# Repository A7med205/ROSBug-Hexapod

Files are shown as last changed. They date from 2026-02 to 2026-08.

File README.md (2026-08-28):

# ROSBug Hexapod

ROSBug is an open-source, Raspberry Pi-based hexapod robot with an onboard
camera, printable CAD, physical-robot software, and a ROS 2 Gazebo simulation.
The Raspberry Pi sends timed points for all 18 joints to a Servo 2040 in
batches over USB. The Servo 2040 runs Pimoroni MicroPython and treats each
batch as an opaque playback job: it validates, calibrates, and applies the
points without knowing whether they were generated by the gait core, posture
core, or another compatible producer.

Hardware and simulation use the same model, inverse kinematics, gait and
posture generators, keyboard mapping, and motion coordinator. Only their
transport adapters and actuator backends differ.

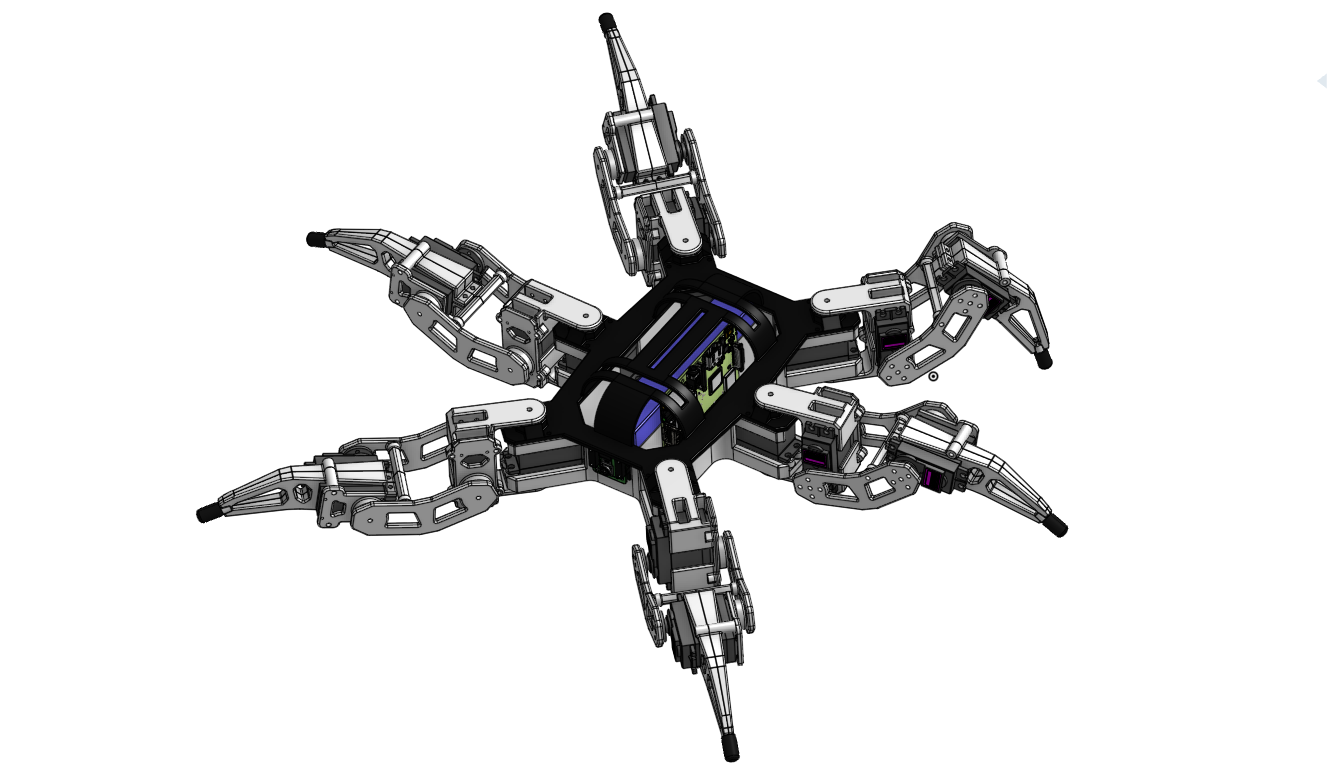
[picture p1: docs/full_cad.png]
Complete ROSBug Hexapod CAD assembly


## Highlights

- Shared, transport-independent Python motion core
- Tripod translation, rotation, diagonal, and orbit gaits
- Smooth elevation, pitch, and roll posture control
- Raspberry Pi to Servo 2040 binary batch protocol
- Pimoroni MicroPython firmware with per-servo calibration
- ROS 2 Humble, Gazebo Sim, RViz, and Docker support
- Editable Onshape CAD and print-ready STL files

## Quick start

### Physical robot

Deploy the runtime directories to the Pi, install the host dependencies, copy
the MicroPython application to the Servo 2040, and start the board interface.
The complete procedure, including BOOTSEL recovery, is in
[Hardware setup](docs/hardware-setup.md).

```bash
python3 -m hardware.board_interface --port /dev/ttyACM0
```

### Docker simulation

On a Linux host with Docker and X11 available:

```bash
./run_sim_docker.sh
```

See [Simulation](docs/simulation.md) for native ROS 2 setup, launch variants,
adapter parameters, and Docker options.

## Documentation

| Topic | Contents |
| --- | --- |
| [Documentation index](docs/README.md) | Task-oriented navigation to every guide |
| [Architecture](docs/architecture.md) | Components, repository layout, and hardware/simulation data flow |
| [Controls](docs/controls.md) | Keyboard commands, operating modes, and posture behavior |
| [Motion model](docs/motion-model.md) | Coordinate frames, IK, gait generation, posture limits, and parameters |
| [Hardware setup](docs/hardware-setup.md) | Pi deployment, dependencies, firmware installation, and startup |
| [Servo 2040](docs/servo2040.md) | MicroPython playback, binary protocol, measured timing, and calibration |
| [Simulation](docs/simulation.md) | ROS 2, Gazebo, RViz, Docker, and simulation parameters |
| [Hardware design](docs/hardware-design.md) | CAD and electronics wiring |
| [Bill of materials](docs/bill-of-materials.md) | Components, printed parts, fasteners, and tools |

## Repository overview

```text
ROSBug-Hexapod/
├── cad/stl/                         printable mechanical parts
├── common/                          shared keyboard input
├── gait_core/                       tripod gait generation
├── posture_core/                    elevation, pitch, and roll generation
├── robot_core/                      model, IK, coordination, and batch types
├── hardware/                        Pi adapter and Servo 2040 MicroPython code
├── ros2_ws/src/hexapod_sim/         ROS 2 simulation package
├── docs/                            guides, diagrams, and demonstrations
├── Dockerfile
├── run_sim_docker.sh
└── requirements.txt
```

## Camera testing

For camera testing, see
[RaspberryPi-WebRTC](https://github.com/TzuHuanTai/RaspberryPi-WebRTC).

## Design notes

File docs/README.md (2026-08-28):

[Project home](../README.md) · Documentation index

# ROSBug documentation

Use this index to find setup instructions, operating guidance, design details,
and technical reference material.

| I want to… | Documentation |
| --- | --- |
| Install and run the physical robot | [Hardware setup](hardware-setup.md) |
| Run Gazebo, RViz, or Docker | [Simulation](simulation.md) |
| Learn the modes and keyboard commands | [Controls](controls.md) |
| Understand the software components and data flow | [Architecture](architecture.md) |
| Understand kinematics, gait, and posture generation | [Motion model](motion-model.md) |
| Inspect the Servo 2040 protocol, playback, and calibration | [Servo 2040](servo2040.md) |
| Inspect the CAD, electronics, and wiring | [Hardware design](hardware-design.md) |
| Find parts, printed components, fasteners, and tools | [Bill of materials](bill-of-materials.md) |

All commands are run from the repository root unless a document explicitly
changes directory.

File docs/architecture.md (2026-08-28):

[Project home](../README.md) · [Documentation index](README.md)

# Architecture

ROSBug uses one transport-independent motion core for the physical robot and
simulation. The adapters differ, but both consume the same timed, 18-joint
`JointBatch` objects.

## Repository layout

```text
ROSBug-Hexapod/
├── cad/stl/                         printable mechanical parts
├── common/
│   └── keyboard_input.py            shared nonblocking keyboard mapping
├── gait_core/
│   └── lite_gait.py                 tripod paths, swings, templates, gait state
├── posture_core/
│   └── posture.py                   elevation, pitch, roll, limits, smoothing
├── robot_core/
│   ├── control.py                   commands and normal/auto/posture modes
│   ├── coordinator.py               shared motion arbitration
│   ├── execution.py                 shared batch-executor result contract
│   ├── feedback.py                  structured command/state feedback
│   ├── model.py                     geometry, frames, fixed-foot transforms, IK
│   └── motion_batch.py              transport-neutral JointBatch and goal IDs
├── hardware/                        physical-robot-only code
│   ├── firmware/                    MicroPython runtime and recovery files
│   ├── batch_executor.py            reusable binary serial batch executor
│   ├── board_interface.py           host keyboard frontend
│   ├── main.py                      Servo 2040 calibration and playback
│   ├── protocol.py                  shared host/MicroPython wire protocol
│   └── calibration.txt              readable calibration constants
├── ros2_ws/src/hexapod_sim/         simulation-only ROS 2 package
│   ├── config/                       ros2_control configuration
│   ├── launch/                       Gazebo and RViz launch files
│   ├── meshes/                       simulation meshes
│   ├── rviz/                         RViz configuration
│   ├── scripts/                      simulation adapter and batch executor
│   └── urdf/                         robot model and Gazebo integration
├── docs/                             documentation and media
├── requirements.txt                 host Python dependency (`pyserial`)
├── run_sim_docker.sh                Docker simulation entry point
└── README.md                         project landing page
```

## Communication

```mermaid
flowchart LR
    subgraph Shared transport-independent core
        KI[common.keyboard_input] -->|Command| COORD[HexapodCoordinator]
        COORD --> GAIT[gait_core]
        COORD --> POSTURE[posture_core]
        GAIT --> MODEL[robot_core model + IK]
        POSTURE --> MODEL
        GAIT --> BATCH[18-joint JointBatch]
        POSTURE --> BATCH
    end

    KB[Keyboard] --> KI
    BATCH --> HW[BoardBatchExecutor]
    HW -->|versioned binary serial frame| BOARD[Servo 2040 MicroPython main.py]
    BOARD -->|calibration + pulse conversion| SERVOS[18 physical servos]
    BOARD -->|ACK / DONE / ERR| HW

    BATCH --> SIM[SimulationBatchExecutor]
    SIM -->|FollowJointTrajectory action| ROSCTRL[ROS 2 joint trajectory controller]
    ROSCTRL --> GZ[Gazebo Sim]
    GZ --> RVIZ[RViz / joint states]
```

The Pi sends timed joint points in batches. The Servo 2040 firmware validates,
calibrates, and plays those points, but intentionally has no knowledge of
whether they came from the gait generator, posture generator, or another
future producer.

| Concern | Hardware | Simulation |
| --- | --- | --- |
| Batch transport | Binary USB serial | `FollowJointTrajectory` action |
| Joint point representation | 18 float32 radians | 18 ROS position values in radians |
| Point timing | Discrete board-clock application; no interpolation | Controller may interpolate between timed points |
| Hardware conversion | Robot radians → calibrated servo degrees → pulses | Not used |
| Completion | Text `ACK` then `DONE`/`ERR` | ROS action result |

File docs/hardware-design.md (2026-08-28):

[Project home](../README.md) · [Documentation index](README.md)

# Hardware design

## CAD

The editable mechanical model is available in the
[ROSBug Hexapod Onshape document](https://cad.onshape.com/documents/2a9acbb79b23a0da46d8b498/w/10c7141c859961b97a14543a/e/498922900873c82099a5cf37).
Print-ready meshes are included in [`cad/stl`](../cad/stl).

Complete ROSBug Hexapod CAD assembly

## Electronics

```mermaid
graph LR
    Battery-->|7.4V|Connector
    Battery-->|GND|Connector

    Battery-->|3 PIN|Alarm[Voltage<br>Alarm]

    Connector-->|"7.4V<br>(solder)"|Buck[Buck<br>Converter]
    Connector-->|"GND<br>(solder)"|Buck
    Connector-->|"7.4V<br>(solder)"|UBEC
    Connector-->|"GND<br>(solder)"|UBEC

    Buck-->|"5V<br>(MicroUSB)"|RPi[-<br>RPi<br>-]
    Buck-->|"GND<br>(MicroUSB)"|RPi
    RPi-->|USB-C|Servo2040[-<br>Servo 2040<br>-]
    RPi-->CAM

    UBEC-->|6V|Servo2040
    UBEC-->|GND|Servo2040
    Servo2040-->|6V|Servos[18× servo]
    Servo2040-->|GND|Servos
    Servo2040-->|Signal|Servos
```

Parts, printed components, fasteners, and tools are listed in the
[bill of materials](bill-of-materials.md).

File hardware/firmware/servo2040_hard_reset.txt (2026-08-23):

Servo 2040 MicroPython recovery / hard reset
================================================

Bundled erase image:
  hardware/firmware/nuke_universal.uf2
  SHA-256: f1d80fcc37161df8cbdf16a58c111208f06234976a470c17699270d212e91754
  Source: Raspberry Pi pico-sdk-prebuilts nuke_universal.uf2

Bundled runtime:
  hardware/firmware/pico-v1.27.0-pimoroni-micropython.uf2
  SHA-256: 5160050bef88dacd43496cd9fcfe14d3a8844d9d640a9a3131f65c5fd833a14c

WARNING: This procedure erases the entire external flash, including the board
runtime and MicroPython filesystem. Back up every file that must be preserved.
Disconnect external servo power and mechanically support the robot before
continuing; leave only the USB connection used for recovery.

1. Enter the RP2040 BOOTSEL bootloader using the reliable full-power sequence:

   a. Stop programs using /dev/ttyACM0.
   b. Disconnect USB and all external power from the Servo 2040.
   c. Wait five seconds.
   d. Press and hold the button labelled BOOT/USR.
   e. While continuing to hold BOOT/USR, reconnect USB.
   f. Keep holding BOOT/USR for 5-10 seconds, then release it.

   The board should enumerate as USB ID 2e8a:0003 and expose a small removable
   volume named RPI-RP2. USB ID 2e8a:0005 means normal MicroPython started and
   the BOOTSEL sequence must be repeated.

     lsusb -d 2e8a:

2. Identify the new partition; do not assume that it is /dev/sda1:

     lsblk -o NAME,SIZE,RM,LABEL,MODEL,MOUNTPOINTS

3. If RPI-RP2 was auto-mounted, use the mount point reported by lsblk in every
   copy command below. Otherwise, replace /dev/sdX1 only after verifying that
   it is the 128 MB removable RPI-RP2 partition, then mount it:

     sudo mkdir -p /mnt/rp2040
     sudo mount -o rw /dev/sdX1 /mnt/rp2040
     ls /mnt/rp2040

   Do not continue unless the selected directory contains INFO_UF2.TXT.

4. From the repository root, copy the bundled erase image to the verified
   RPI-RP2 mount point:

     sudo cp hardware/firmware/nuke_universal.uf2 /mnt/rp2040/
     sync

   The volume should disconnect while the erase image runs. Wait at least ten
   seconds. The blank board normally returns to BOOTSEL; if it does not, repeat
   step 1. The old mount is invalid after the disconnect, and /mnt/rp2040 may
   now be only an empty ordinary directory. Identify the new RPI-RP2 partition
   again; its device name may change, for example from /dev/sda1 to /dev/sdb1:

     lsusb -d 2e8a:
     lsblk -o NAME,SIZE,RM,LABEL,MODEL,MOUNTPOINTS
     mountpoint /mnt/rp2040

   If the new RPI-RP2 partition is not auto-mounted, mount its newly verified
   device name before continuing. For example, if lsblk now reports /dev/sdb1:

     sudo mount -o rw /dev/sdb1 /mnt/rp2040

5. Verify INFO_UF2.TXT again, then flash the bundled Pimoroni MicroPython
   runtime:

     ls /mnt/rp2040
     sudo cp hardware/firmware/pico-v1.27.0-pimoroni-micropython.uf2 /mnt/rp2040/
     sync

   The bootloader volume should disconnect automatically as MicroPython boots.

6. Wait for the serial device to appear, then restore protocol.py before
   main.py because main.py imports it at startup:

     ls -l /dev/ttyACM*
     mpremote connect /dev/ttyACM0 cp hardware/protocol.py :protocol.py
     mpremote connect /dev/ttyACM0 cp hardware/main.py :main.py

7. Reset or reconnect the board normally. The application intentionally waits
   five seconds during startup; wait for READY 1 before sending a batch.

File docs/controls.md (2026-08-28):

[Project home](../README.md) · [Documentation index](README.md)

# Controls and operating modes

The keyboard controls and coordinator behavior are identical for hardware and
simulation.

## Modes and state behavior

- At startup, the coordinator rejects counted motion until the standup `u`
  command or the skip assertion completes.
- `normal` accepts bare movement keys as continuous commands. A new movement
  direction is latched and applied at the next full-step midpoint.
- `auto` only accepts a movement command with an integer step count of at least
  two. Auto jobs start and end stationary, and are aborted by `0`.
- `posture` starts from canonical stationary and accepts relative elevation,
  pitch, and roll changes. Elevation can coexist with either tilt. Pitch and
  roll cannot coexist; reset the active tilt before selecting the other axis.

## Keyboard controls

| Key | Command |
| --- | --- |
| `u` | Explicit standup sequence |
| `k` | Skip standup and assert that the robot is already standing |
| `j` | Sit down from stationary and restore the standup lock |
| `0` | Graceful gait stop; in posture, interrupt and then return neutral |
| `t` | Cycle auto → posture → normal → auto (auto is the default) |
| `w`, `d`, `s`, `a` | Move `+Y`, `+X`, `-Y`, `-X` |
| `q`, `e`, `z`, `c` | Diagonal motion, or orbit motion after pressing `m` |
| `m` | Toggle the `q/e/z/c` mapping between diagonal and orbit |
| `o`, `p` | Rotate counterclockwise / clockwise |
| `5w` | Example auto command: move `+Y` for five counted steps |
| `5[` / `5]` | Lower / raise the body by 5 mm in posture mode |
| `5.`, `5,` | Add / subtract 5° pitch in posture mode |
| `5'`, `5;` | Add / subtract 5° roll in posture mode |
| `r` | Reset pitch or roll to zero while preserving elevation |
| Backspace | Delete the last numeric-prefix digit |
| Escape | Clear the numeric prefix |
| `x` | Quit after the current batch |

| Simulation keyboard controls | Simulation posture controls |
| --- | --- |
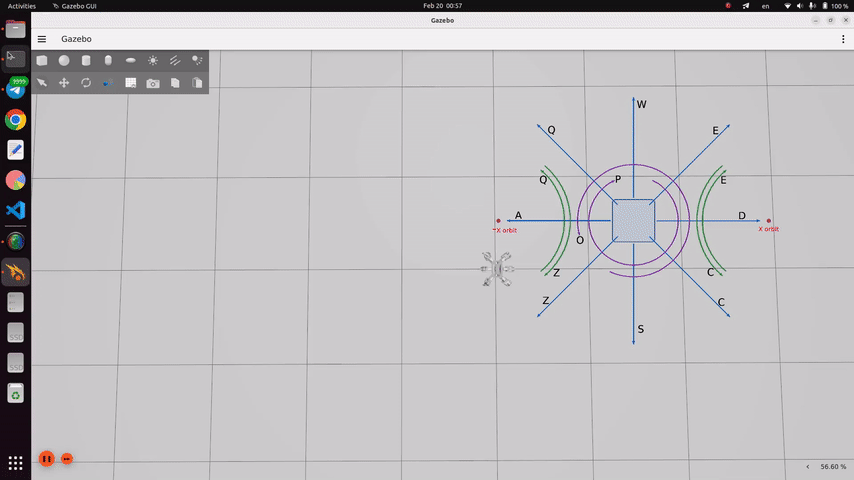
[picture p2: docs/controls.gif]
Simulation keyboard controls
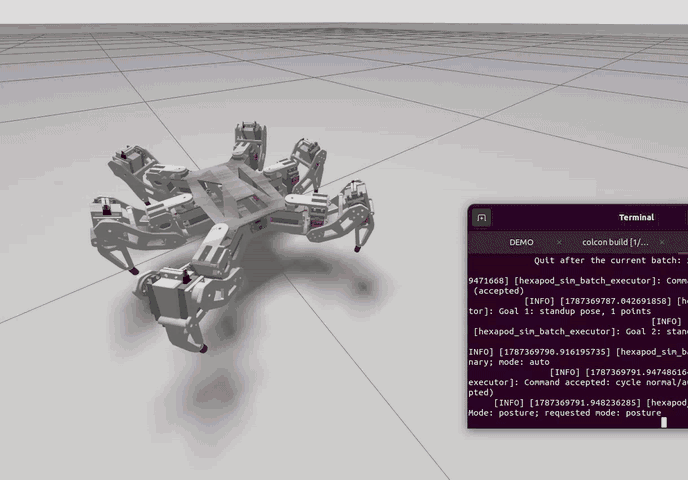
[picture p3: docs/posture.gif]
Simulation posture controls
|  |  |

Posture commands require a numeric prefix. `[` and `]` lower and raise
elevation by the prefixed number of millimetres; pitch and roll numbers are
relative degree changes from the confirmed pose. Every elevation change is
clamped to the 27.5–104 mm scaled objective-height envelope.

During an active posture command, the first `0` discards remaining points
after the current 25-point boundary and enters `POSTURE_HOLD`; a second `0`
from that hold returns to the stationary objective elevation and zero tilt.
`r` zeros the active tilt without changing elevation.

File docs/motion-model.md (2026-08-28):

[Project home](../README.md) · [Documentation index](README.md)

# Motion model

Unless stated otherwise, lengths are metres internally and angles are radians.

## High-level motion logic

1. Keyboard input becomes a transport-neutral command. Input is not queued;
   after terminal draining, only the latest command remains.
2. The coordinator refuses motion until standing readiness is established and
   gives either gait or posture exclusive control of joint output.
3. The gait core generates tripod motion by transforming body displacement
   into the local tip displacement that keeps each stance foot fixed in the
   world.
4. Pull paths advance the base model in 20 ms increments until any selected
   tripod tip reaches the 40 mm travel radius. A full path has two halves and
   a neutral midpoint.
5. Swing paths trace the reversed pull path in x/y. Their z coordinate adds
   `swing_height × sin(πs)`, producing a ground-to-ground arc for start/stop
   halves or a continuous arc across a full step.
6. After IK conversion, synchronized future-setpoint joint templates are
   retained.
7. The six leg sequences in a phase must have identical lengths.
8. A half step is used at the start and end of a walk to leave and return to
   neutral.
9. Direction changes are applied at the full-step midpoint, where two
   trajectory-type halves are joined.
10. Each half-step-sized `JointBatch` is handed to the selected adapter. A new
    batch is not issued until the current one reports completion.
11. Posture movements happen while the robot tips are in neutral position.

This top view uses actual leg-1 Cartesian points generated by the core. It
compares `t1` (`+Y` body translation), `t7` (clockwise body rotation), and the
two hybrid full pulls produced when direction changes at home.

Leg-local pull paths and midpoint direction changes

The dashed circle is centred on the neutral tip. Because limit detection is
sampled, the final generated point may lie slightly beyond the 40 mm circle on
the first sample that reaches the limit.

## Coordinate and joint conventions

- Body `+Y` is forward, body `+X` is right, and body `+Z` is up.
- Roll, pitch, and yaw rotate about body `+X`, `+Y`, and `+Z` respectively.
  Positive rotations follow the right-hand rule.
- Every leg has a local frame whose `+X` points radially outward from its body
  mount, `+Y` is tangential, and `+Z` matches body up.
- Joint `j1` is coxa/base rotation, `j2` is femur/hip rotation, and `j3` is
  tibia/knee rotation. IK zero `(0, 0, 0)` means the complete leg is straight
  and fully extended along local `+X`.
- Shared and hardware names are `j<leg><joint>`; ROS names insert `l`, so
  hardware `j12` corresponds to ROS `jl12`.
- Shared 18-value batches are leg-major:
  `j11,j12,j13,j21,j22,j23,...,j61,j62,j63`.

| Leg | Body mount x | Body mount y | Local heading | Tripod | Location |
| ---: | ---: | ---: | ---: | :---: | --- |
| 1 | -53.5 mm | +90.0 mm | +135° | A | front-left |
| 2 | -70.0 mm | 0.0 mm | +180° | B | middle-left |
| 3 | -53.5 mm | -90.0 mm | -135° | A | rear-left |
| 4 | +53.5 mm | +90.0 mm | +45° | B | front-right |
| 5 | +70.0 mm | 0.0 mm | 0° | A | middle-right |
| 6 | +53.5 mm | -90.0 mm | -45° | B | rear-right |

Top view of the hexapod showing the base and leg frame orientations and tripod membership

## Shared kinematic model

| Parameter | Value |
| --- | ---: |
| Coxa length `l1` | 38.5 mm |
| Femur length `l2` | 70.0 mm |
| Tibia length `l3` | 102.0 mm |
| Neutral local tip | `(x, y, z) = (110, 0, -50)` mm |
| Stationary objective elevation `-home_z` | 50 mm |
| Neutral IK angles per leg | approximately `(0°, -45.096°, +122.591°)` |
| Femur/tibia planar reach after coxa | 32–172 mm |

The IK first solves coxa rotation from local tip x/y, subtracts the coxa
length, and then solves the femur/tibia triangle. Gait templates stay inside
the configured tip radius. Posture targets are checked as complete six-leg
body poses.

## Gait configuration

| Parameter | Value |
| --- | ---: |
| Sample period / rate | 20 ms / 50 Hz |
| Tip travel limit radius | 40 mm |
| Swing height | 25 mm |
| `+X`, `+Y`, diagonal component speed | 0.10 m/s |
| Self-rotation angular speed | 0.40 rad/s |
| Orbit angular speed | 0.30 rad/s |
| External orbit radius | 0.30 m |
| Standup local tip z | +10 mm |
| Standup descent speed | 0.05 m/s |
| Standup pose hold | 2.0 s |
| Standup descent | 60 points / 1.2 s |
| Sit-down reverse motion | 60 points / 1.2 s |

## Posture configuration

Posture trajectories use a 20 ms cubic smoothstep profile.

| Parameter | Value |
| --- | ---: |
| Elevation maximum velocity | 30 mm/s |
| Elevation maximum acceleration | 50 mm/s² |
| Pitch/roll maximum velocity | 10°/s |
| Pitch/roll maximum acceleration | 40°/s² |
| Maximum batch | 25 points / 0.5 s |
| Operating elevation/angular-limit scale | 0.9 |
| Raw objective elevation knots | 25, 50, 80, 98, 110 mm |
| Minimum operating objective elevation | 27.5 mm |
| Stationary objective elevation `-home_z` | 50 mm |
| Maximum operating objective elevation | 104 mm |
| IK boundary-search iterations | 52 |
| Neutral tolerance | `1e-9` |

Objective elevation is derived from the kinematic model. The stationary value
is `-home_z`. The operating scale contracts every raw elevation knot toward
that stationary objective and scales its pitch/roll limit by the same factor.

| Operating objective elevation | Raw roll | Applied roll | Raw pitch | Applied pitch |
| ---: | ---: | ---: | ---: | ---: |
| 27.5 mm | 0° | 0° | 0° | 0° |
| 50 mm | 12° | 10.8° | 12° | 10.8° |
| 77 mm | 20° | 18° | 25° | 22.5° |
| 93.2 mm | 10° | 9° | 12° | 10.8° |
| 104 mm | 0° | 0° | 0° | 0° |

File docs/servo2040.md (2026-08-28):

[Project home](../README.md) · [Documentation index](README.md)

# Servo 2040 firmware and protocol

The physical adapter sends timed batches of 18-joint setpoints to the Servo
2040 over USB serial. The board runs Pimoroni MicroPython and acts as a small,
generation-agnostic batch player: it validates the frame, converts robot
angles through per-servo calibration, and applies the points at their stated
period. It has no knowledge of whether a batch came from gait generation,
posture generation, or another compatible producer.

## Protocol and playback

| Parameter | Value |
| --- | ---: |
| Protocol magic / version / type | `HXGB` / 1 / batch type 1 |
| Joint values per point | 18 float32 radians / 72 bytes |
| Fixed frame overhead | 28-byte header + 4-byte CRC |
| Frame size | `32 + 72 × point_count` bytes |
| Maximum points per frame | 64 |
| Accepted sample-period range | 1–1000 ms |
| Default serial configuration | `/dev/ttyACM0`, 115200 baud |
| Firmware boot wait | 5 s |

The header contains magic, protocol version, message type, header size,
session ID, unique goal ID, joint count, point count, sample period, and
payload length. The board rejects malformed, stale, or CRC-invalid goals.
Joint payload values are trusted after the CRC succeeds and are unpacked only
during playback. Retries reuse the same session/goal ID and are idempotent.

## Measured batch handoff timing

A diagnostic build was tested on trajectory 7 using continuous 24-point
batches at the 20 ms sample period. Goals 35–39 produced these steady-state
ranges; startup, user idle, and the intentional stand-up hold were excluded:

| Stage | Diagnostic range |
| --- | ---: |
| Pi completion processing before the next executor call | 1.2–3.0 ms |
| Host batch encoding and CRC | 0.29–0.34 ms |
| Host USB write and flush | 21.57–21.65 ms |
| Board header receipt and validation | 1.45–1.46 ms |
| Board payload receipt | 18.49–18.64 ms |
| Board native CRC calculation | 0.70–0.73 ms |
| Board garbage collection | 3.94–5.48 ms |
| Board ACK formatting and flush | 0.78–0.80 ms |
| First-point deadline wait after a late-frame reset | 0.42–0.51 ms |
| First joint conversion and servo update | 10.86–11.07 ms |
| **Raw carried-deadline miss per batch** | **40.53–42.51 ms** |

Host and board rows are views of some of the same USB transfer and therefore
must not be added together as independent sequential stages.

## Channel order and calibration

The incoming vector is leg-major, but physical channels are joint-major:

| Board channels | Joints in channel order |
| --- | --- |
| 1–6 | `j11, j21, j31, j41, j51, j61` |
| 7–12 | `j12, j22, j32, j42, j52, j62` |
| 13–18 | `j13, j23, j33, j43, j53, j63` |

For each joint:

```text
servo_deg = s × robot_deg + b
pulse_us   = 1500 + k × servo_deg
```

`k+` is used for non-negative servo degrees and `k-` for negative servo
degrees. Pulses are clamped to 500–2500 µs. These are the runtime values in
`hardware/main.py`:

| Joint | `s` | `b` (deg) | `k+` (µs/deg) | `k-` (µs/deg) |
| --- | ---: | ---: | ---: | ---: |
| `j11` | +1 | 0 | 10.6667 | 10.8889 |
| `j12` | -1 | -84 | 11.1556 | 10.8889 |
| `j13` | +1 | -121 | 10.4444 | 11.3333 |
| `j21` | +1 | 0 | 10.3333 | 11.3333 |
| `j22` | -1 | -69 | 10.5556 | 12.0000 |
| `j23` | +1 | -114 | 11.1667 | 11.1667 |
| `j31` | +1 | 0 | 11.1111 | 10.6667 |
| `j32` | -1 | -79 | 11.1111 | 10.8889 |
| `j33` | +1 | -121 | 11.0000 | 10.6667 |
| `j41` | +1 | 0 | 10.5556 | 10.8889 |
| `j42` | -1 | -74 | 11.1111 | 11.0000 |
| `j43` | +1 | -118 | 10.7778 | 11.1111 |
| `j51` | +1 | 0 | 12.0000 | 11.1111 |
| `j52` | -1 | -67 | 10.6667 | 11.1111 |
| `j53` | +1 | -112 | 10.6667 | 10.8889 |
| `j61` | +1 | 0 | 10.8889 | 11.1111 |
| `j62` | -1 | -78 | 11.5556 | 10.4444 |
| `j63` | +1 | -121 | 11.0000 | 10.5556 |

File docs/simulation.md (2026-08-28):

[Project home](../README.md) · [Documentation index](README.md)

# Simulation

## ROS 2 and RViz

Build the package in a ROS 2 Humble environment:

```bash
cd ros2_ws
source /opt/ros/humble/setup.bash
colcon build --symlink-install
source install/setup.bash
```

Launch Gazebo Sim with RViz in the first terminal:

```bash
ros2 launch hexapod_sim robot.launch.py sim:=true rviz:=true use_sim_time:=true
```

In a second sourced terminal, run the shared keyboard controller:

```bash
cd ros2_ws
source /opt/ros/humble/setup.bash
source install/setup.bash
ros2 run hexapod_sim sim_interface.py
```

The adapter parameters can be overridden through ROS arguments:

```bash
ros2 run hexapod_sim sim_interface.py --ros-args \
  -p action_name:=/joint_trajectory_controller/follow_joint_trajectory \
  -p wait_timeout:=10.0
```

| Launch argument | Default | Effect |
| --- | ---: | --- |
| `sim` | `true` | Starts Gazebo Sim, spawns the robot, bridge, and ros2_control controllers |
| `rviz` | `false` | Starts RViz with `rviz/config.rviz` |
| `use_sim_time` | `true` | Selects the Gazebo `/clock` for ROS nodes |

Use `ros2 launch hexapod_sim robot.launch.py --show-args` for these and the
version-dependent arguments forwarded by the Gazebo launch file.

Common launch variants:

```bash
# Gazebo Sim only (all defaults)
ros2 launch hexapod_sim robot.launch.py

# Gazebo Sim and RViz
ros2 launch hexapod_sim robot.launch.py rviz:=true

# RViz-only model inspection; no trajectory action server is created
ros2 launch hexapod_sim robot.launch.py sim:=false rviz:=true use_sim_time:=false
```

Do not run `sim_interface.py` with the RViz-only variant unless another node
provides the configured trajectory action server.

## Docker

The Docker image uses `osrf/ros:humble-desktop-full`, copies the checkout,
installs the dependencies declared by `hexapod_sim`, and builds the ROS
workspace. From the repository root, build and run Gazebo, RViz, and the
interactive keyboard interface with:

```bash
./run_sim_docker.sh
```

The script forwards the host X11 display, host networking, the terminal, and
`/dev/dri` when available. It rebuilds with Docker's layer cache before each
run. The resulting desktop image is approximately 4 GB. To reuse an existing
image or omit RViz:

```bash
./run_sim_docker.sh --no-build
./run_sim_docker.sh --no-rviz
```

Run `./run_sim_docker.sh --help` for image-name and environment overrides.
Closing the keyboard interface also stops the launch process and removes the
container. The host must provide Docker, `xhost`, an X11-compatible `DISPLAY`,
and access to the Docker daemon.

## Simulation-only parameters

| Parameter | Value |
| --- | ---: |
| Gazebo spawn pose | `(x, y, z) = (0, 0, 0.25)` m |
| ros2_control update rate | 100 Hz |
| URDF revolute limits | `[-π, +π]` rad |
| URDF joint velocity limit | `2π` rad/s |
| URDF joint effort limit | 1000 |
| ros2_control initial `j1/j2/j3` | `0, -0.955, 2.216` rad |
| Tip friction `mu1`, `mu2` | 1.2, 1.2 |
| Tip contact `kp`, `kd` | `1e6`, 100 |
| Tip contact `minDepth`, `maxVel` | 0.001 m, 0.1 m/s |

The controller uses position commands and position/velocity state interfaces.
The shared neutral IK pose is approximately `(0, -0.787, 2.140)` rad per leg.

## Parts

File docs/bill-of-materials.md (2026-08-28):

[Project home](../README.md) · [Documentation index](README.md)

# Bill of materials

Amazon links open a live Amazon UK search for the required specification.
Reference prices were checked on 21 August 2026 and include the quantity.

## Electronics and mechanical parts

| Item | Qty. | Source | Reference price |
| --- | ---: | --- | ---: |
| Raspberry Pi 3 Model B+ | 1 | [Amazon UK](https://www.amazon.co.uk/s?k=Raspberry+Pi+3+Model+B%2B) | £43.40 |
| 32 GB microSDHC card | 1 | [Amazon UK](https://www.amazon.co.uk/s?k=32GB+microSDHC+card+Class+10) | £8.99 |
| MG996R metal-gear servo | 18 | [Amazon UK](https://www.amazon.co.uk/s?k=MG996R+servo+6+pack) | £89.97 |
| Raspberry Pi Camera Module v2.1 | 1 | [Amazon UK](https://www.amazon.co.uk/s?k=Raspberry+Pi+Camera+Module+v2.1) | £8.70 |
| XL4015 adjustable DC-DC buck converter | 1 | [Amazon UK](https://www.amazon.co.uk/s?k=XL4015+5A+buck+converter) | £6.38 |
| Servo 2040 controller | 1 | [Pimoroni](https://shop.pimoroni.com/products/servo-2040) | £24.00 |
| 6200 mAh 7.4 V 60C LiPo battery | 1 | [Amazon UK](https://www.amazon.co.uk/s?k=6200mAh+7.4V+60C+LiPo+battery) | £29.99 |
| 2–8S 8 A UBEC with selectable 6 V output | 1 | [Amazon UK](https://www.amazon.co.uk/s?k=2-8S+8A+UBEC+6V) | £19.99 |
| MG996R-compatible metal servo horn | 18 | [Amazon UK](https://www.amazon.co.uk/s?k=MG996R+metal+servo+horn+25T) | £18.99 |
| 628-2Z deep-groove bearing | 18 | [Amazon UK](https://www.amazon.co.uk/s?k=628-2Z+bearing) | £13.99 |
| 7 mm rubber tip | 6 | [Amazon UK](https://www.amazon.co.uk/s?k=7mm+rubber+end+caps) | £5.99 |
| **Priced parts total** | | | **£270.39** |

The total excludes printed parts, filament, unpriced fasteners, delivery, and
price changes after the reference date.

## Printed parts

| Part | Qty. | Part | Qty. |
| --- | ---: | --- | ---: |
| `base_` | 1 | `cover_2` | 1 |
| `cam_mount_` | 1 | `cam_shield` | 2 |
| `coxa_1` | 6 | `coxa_2` | 6 |
| `bearing_link` | 18 | `spacer` | 18 |
| `bearing_holder` | 6 | `bearing_holder_2` | 6 |
| `femur_1` | 6 | `femur_2` | 6 |
| `bearing_` | 18 | `tibia_1_` | 6 |
| `tibia_2_` | 6 | | |

## Fasteners

| Fastener | Qty. | Fastener | Qty. |
| --- | ---: | --- | ---: |
| M2.5 × 36 pan-head screw | 48 | M2 × 0.4 × 12 hex screw | 4 |
| M3 × 0.5 × 6 hex screw | 72 | M3 × 0.5 × 8 hex screw | 36 |
| M3 × 0.5 × 10 hex screw | 48 | M3 × 0.5 × 12 hex screw | 36 |
| M3 × 0.5 × 16 hex screw | 12 | M3 × 0.5 × 35 hex screw | 18 |
| M3 × 0.5 hex nut | 66 | | |

## Tools and additional materials

| Item | Qty. | Source | Reference price |
| --- | ---: | --- | ---: |
| LiPo balance charger | 1 | [Amazon UK](https://www.amazon.co.uk/s?k=LiPo+battery+balance+charger) | £34.99 |
| Digital multimeter | 1 | [Amazon UK](https://www.amazon.co.uk/s?k=digital+multimeter) | £12.99 |
| 1 m 20 AWG silicone wire | 2 | [Amazon UK](https://www.amazon.co.uk/s?k=1m+20AWG+silicone+wire) | £9.98 |
| Jumper-wire set | 2 | [Amazon UK](https://www.amazon.co.uk/s?k=jumper+wires+Arduino) | £7.98 |
| M3 assorted screw set | 2 | [Amazon UK](https://www.amazon.co.uk/s?k=M3+assorted+screw+set) | £16.98 |
| M2 assorted screw set | 1 | [Amazon UK](https://www.amazon.co.uk/s?k=M2+assorted+screw+set) | £6.49 |
| M3 × 45 mm screw set | 1 | [Amazon UK](https://www.amazon.co.uk/s?k=M3+x+45mm+socket+screws) | £6.49 |
| M2.5 × 35 mm screw set | 1 | [Amazon UK](https://www.amazon.co.uk/s?k=M2.5+x+35mm+screws) | £9.99 |
| USB-A to USB-C cable | 1 | [Amazon UK](https://www.amazon.co.uk/s?k=USB-A+to+USB-C+cable) | £6.99 |
| 18 AWG SM-2P plug lead | 2 | [Amazon UK](https://www.amazon.co.uk/s?k=18AWG+SM-2P+plug+lead) | £9.99 |
| 14 AWG battery plug lead | 1 | [Amazon UK](https://www.amazon.co.uk/s?k=14AWG+battery+connector+lead) | £6.99 |
| Micro-USB power cable | 3 | [Amazon UK](https://www.amazon.co.uk/s?k=Micro+USB+power+cable) | £8.99 |
| 2–8S LiPo voltage alarm | 3 | [Amazon UK](https://www.amazon.co.uk/s?k=2-8S+LiPo+voltage+alarm) | £7.49 |
| Temperature-controlled soldering-iron kit | 1 | [Amazon UK](https://www.amazon.co.uk/s?k=temperature+controlled+soldering+iron+kit) | £15.99 |
| **Tools and materials total** | | | **£162.33** |

The total excludes delivery and price changes after the reference date.

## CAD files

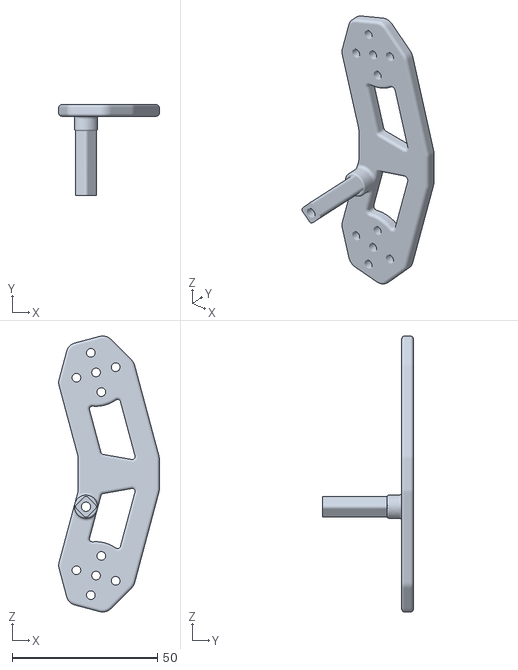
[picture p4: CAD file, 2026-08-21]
cad/stl/femur_2.STL
34.7 x 31.2 x 95.1

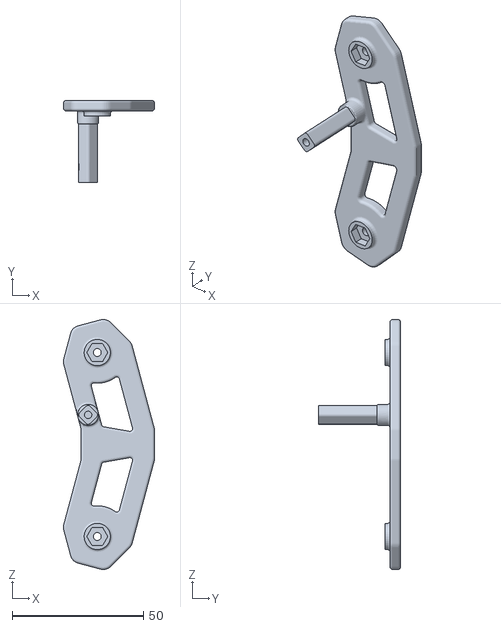
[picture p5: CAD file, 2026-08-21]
cad/stl/femur_1.STL
34.7 x 31.2 x 95.1

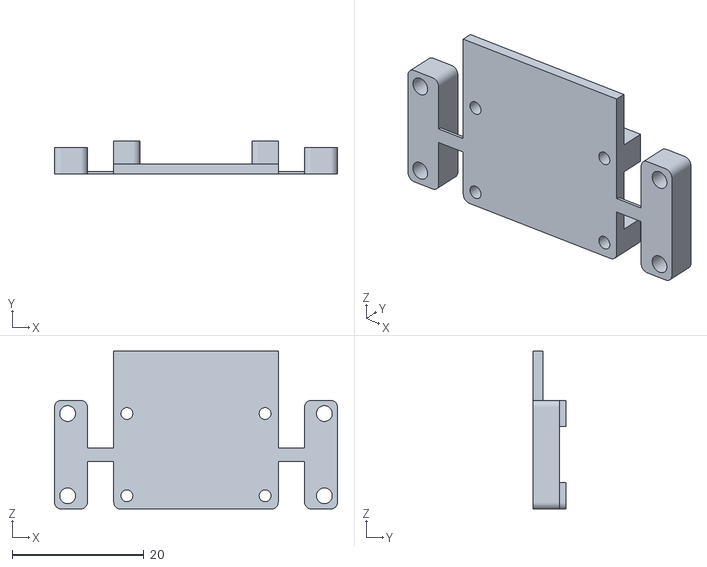
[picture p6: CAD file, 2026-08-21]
cad/stl/cam_mount+cam_shield.STL
43.0 x 5.00 x 24.0

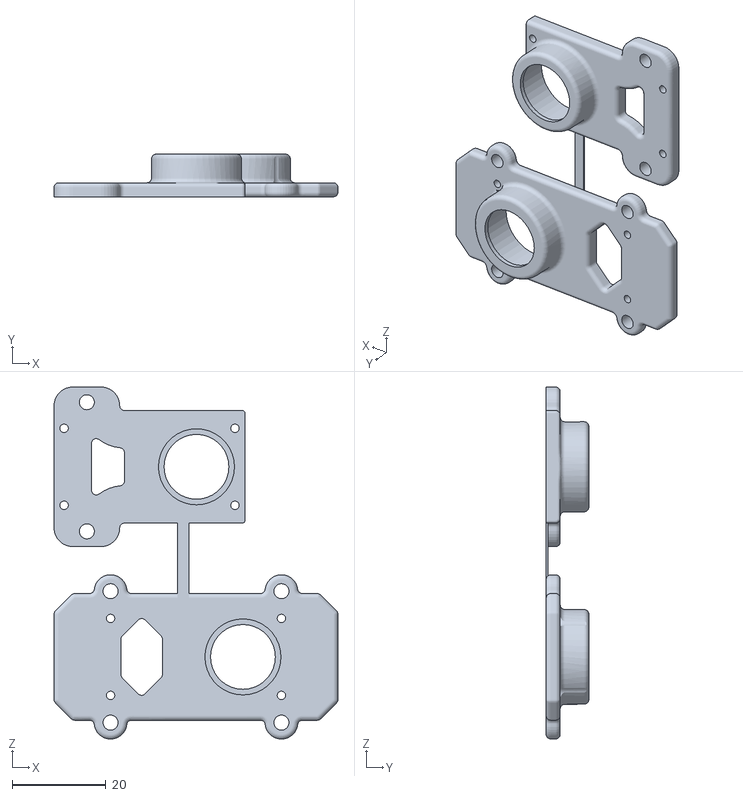
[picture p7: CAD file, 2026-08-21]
cad/stl/bearing_holder+bearing_holder_2.STL
60.5 x 9.10 x 75.0

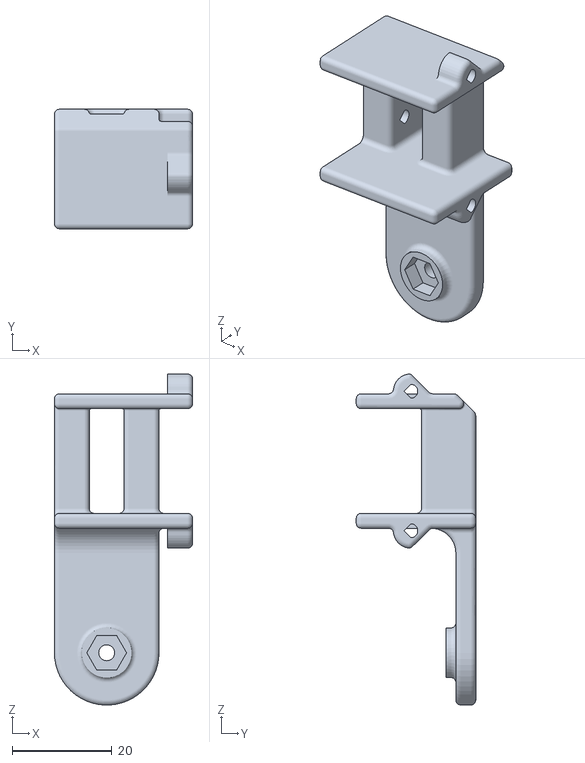
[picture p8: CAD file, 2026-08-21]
cad/stl/coxa_1.STL
27.8 x 24.0 x 66.5

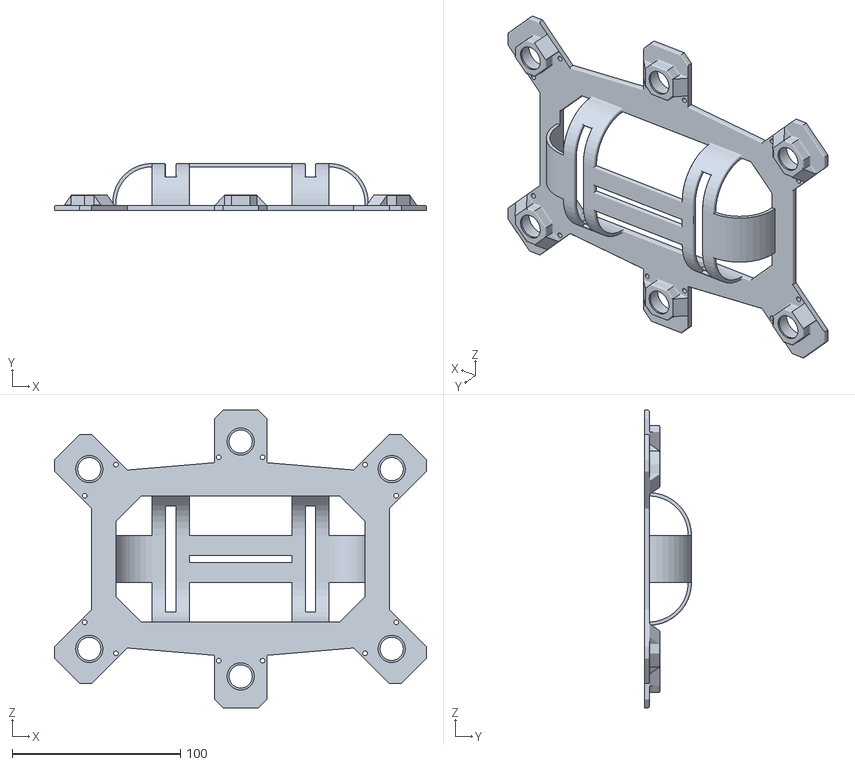
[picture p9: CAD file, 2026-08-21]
cad/stl/cover_2.STL
221.3 x 28.0 x 177.0

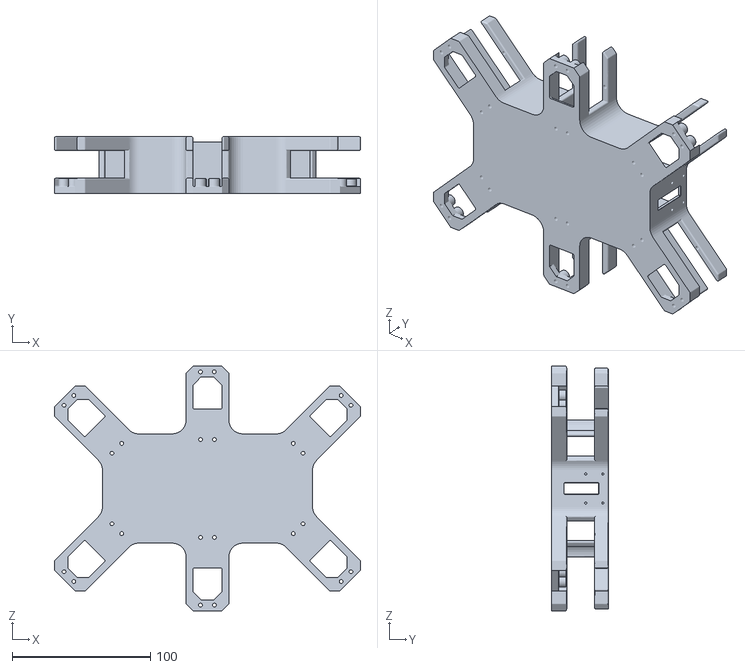
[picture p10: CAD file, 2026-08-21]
cad/stl/base_.STL
221.3 x 41.0 x 177.0

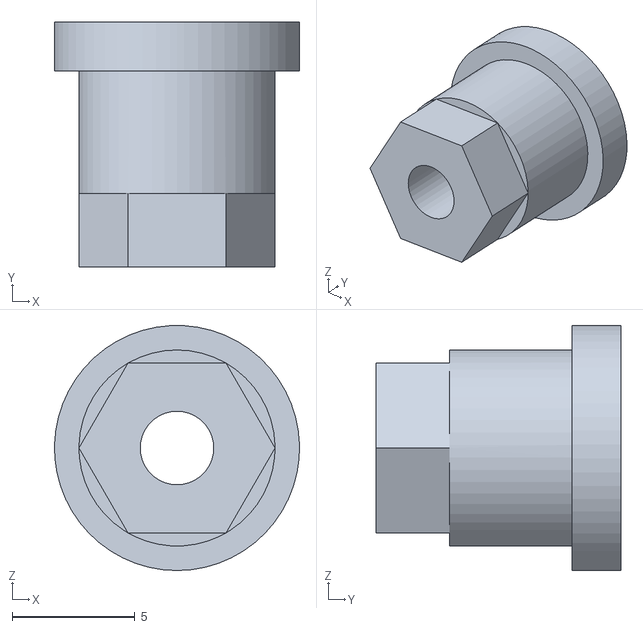
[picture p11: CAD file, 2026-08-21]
cad/stl/bearing_link.STL
10.00 x 10.0 x 10.0

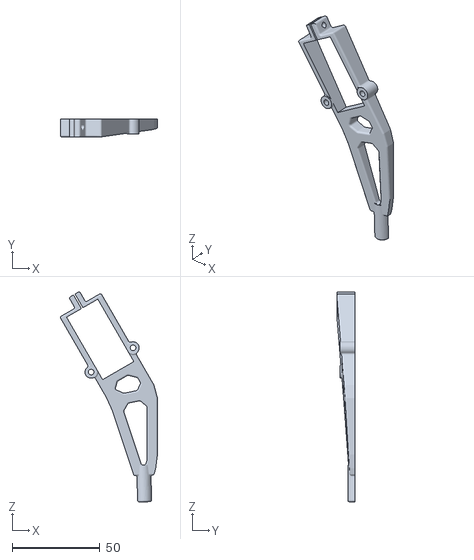
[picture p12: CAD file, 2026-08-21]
cad/stl/tibia_2_.STL
55.1 x 10.00 x 119.4

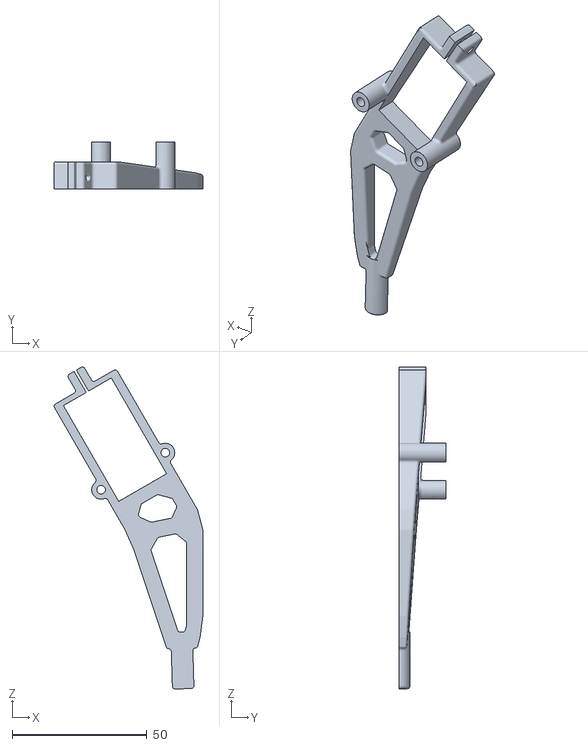
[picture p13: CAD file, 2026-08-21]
cad/stl/tibia_1_.STL
55.1 x 17.3 x 119.4

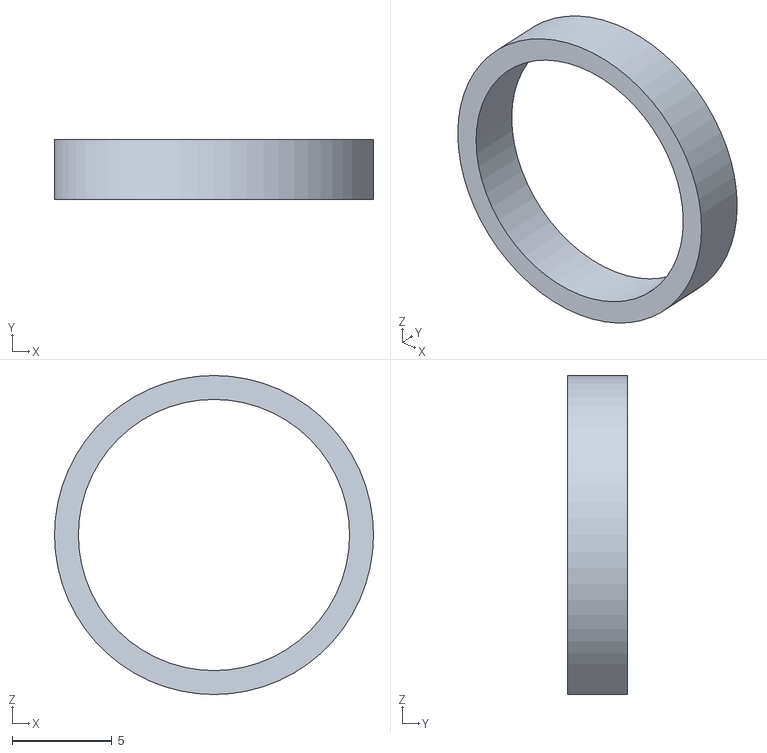
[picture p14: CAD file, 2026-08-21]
cad/stl/spacer.STL
16.0 x 3.00 x 16.0

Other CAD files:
cad/stl/coxa_2.STL

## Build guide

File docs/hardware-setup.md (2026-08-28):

[Project home](../README.md) · [Documentation index](README.md)

# Hardware setup

The hardware adapter runs on the robot's Raspberry Pi. From a machine with
this repository open, create the destination and copy the runtime files:

```bash
ssh pi@<ip-address> 'mkdir -p /home/pi/ROSBug-Hexapod'
scp -r \
  common \
  robot_core \
  gait_core \
  posture_core \
  hardware \
  requirements.txt \
  pi@<ip-address>:/home/pi/ROSBug-Hexapod/
```

SSH into the Pi before running the remaining commands:

```bash
ssh pi@<ip-address>
cd /home/pi/ROSBug-Hexapod
```

These instructions assume the Servo 2040 is attached to the Pi over USB.

## Install host dependencies

```bash
python3 -m pip install -r requirements.txt
python3 -m pip install mpremote
```

## Install or update the Servo 2040 software

The repository includes the Pimoroni MicroPython `v1.27.0` RP2040 runtime used
by the Servo 2040:

| Runtime property | Value |
| --- | --- |
| Bundled UF2 | `hardware/firmware/pico-v1.27.0-pimoroni-micropython.uf2` |
| Target | Raspberry Pi RP2040 (`0xe48bff56`) |
| Size | 1,300,992 bytes / 2,541 UF2 blocks |
| SHA-256 | `5160050bef88dacd43496cd9fcfe14d3a8844d9d640a9a3131f65c5fd833a14c` |
| Upstream release | [Pimoroni Pico MicroPython v1.27.0](https://github.com/pimoroni/pimoroni-pico/releases/tag/v1.27.0) |

Routine updates only require copying `main.py` and `protocol.py`; do not
reflash the UF2 for normal application changes. If the MicroPython runtime is
missing or corrupt, follow the
[Servo 2040 hard-reset procedure](../hardware/firmware/servo2040_hard_reset.txt).
It explains the long BOOT hold, USB disconnect/reconnect, `RPI-RP2` identity
check, mount-device changes such as `sda1` to `sdb1`, flashing, and restoring
the application files.

Pimoroni's
[installation guide](https://github.com/pimoroni/pimoroni-pico/blob/main/setting-up-micropython.md)
identifies the generic `pico-...-pimoroni-micropython.uf2` build for Servo 2040
and other non-wireless RP2040 boards.

Copy both MicroPython files to the board; `main.py` imports `protocol.py` from
its filesystem:

```bash
mpremote connect /dev/ttyACM0 cp hardware/protocol.py :protocol.py
mpremote connect /dev/ttyACM0 cp hardware/main.py :main.py
```

## Run the physical robot

```bash
python3 -m hardware.board_interface --port /dev/ttyACM0
```

| Argument | Default | Meaning |
| --- | ---: | --- |
| `--port` | `/dev/ttyACM0` | Servo 2040 serial device |
| `--baudrate` | `115200` | PySerial baud setting |
| `--response-timeout` | `8.0` s | ACK/DONE timeout, including the five-second firmware boot delay |

Wait for `READY 1` before diagnosing an initial timeout. The firmware accepts
one batch at a time. Playback carries the next point deadline across batches;
a late frame applies its first point immediately and starts a fresh board-clock
cadence.

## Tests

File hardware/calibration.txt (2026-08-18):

# Angle-to-pulse calibration (µs/deg), asymmetric slopes per joint; Center = 1500us
CENTER_PULSE = 1500.0
CALIBRATION = {
    "j11": (10.6667, 10.8889),
    "j12": (11.1556, 10.8889),
    "j13": (10.4444, 11.3333),
    "j21": (10.3333, 11.3333),
    "j22": (10.5556, 12.0000),
    "j23": (11.1667, 11.1667),
    "j31": (11.1111, 10.6667),
    "j32": (11.1111, 10.8889),
    "j33": (11.0000, 10.6667),
    "j41": (10.5556, 10.8889),
    "j42": (11.1111, 11.0000),
    "j43": (10.7778, 11.1111),
    "j51": (12.0000, 11.1111),
    "j52": (10.6667, 11.1111),
    "j53": (10.6667, 10.8889),
    "j61": (10.8889, 11.1111),
    "j62": (11.5556, 10.4444),
    "j63": (11.0000, 10.5556),
}

# Robot-to-servo angle mapping (degrees) per robot_to_servo.txt
# model: servo_deg = s * robot_deg + b
ROBOT_TO_SERVO = {
    "j11": ( 1.0,    0.0),
    "j12": (-1.0,  -84.0),
    "j13": ( 1.0, -121.0),

    "j21": ( 1.0,    0.0),
    "j22": (-1.0,  -69.0),
    "j23": ( 1.0, -114.0),

    "j31": ( 1.0,    0.0),
    "j32": (-1.0,  -79.0),
    "j33": ( 1.0, -121.0),

    "j41": ( 1.0,    0.0),
    "j42": (-1.0,  -74.0),
    "j43": ( 1.0, -118.0),

    "j51": ( 1.0,    0.0),
    "j52": (-1.0,  -67.0),
    "j53": ( 1.0, -112.0),

    "j61": ( 1.0,    0.0),
    "j62": (-1.0,  -78.0),
    "j63": ( 1.0, -121.0),
}

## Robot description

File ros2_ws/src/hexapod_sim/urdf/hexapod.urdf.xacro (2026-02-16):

<?xml version="1.0"?>
<robot name="hexapod" xmlns:xacro="http://www.ros.org/wiki/xacro">

  <!-- Included files. -->
  <xacro:include filename="xacro_include/joint_control_macro.xacro"/> 
  <xacro:include filename="xacro_include/leg_macro.xacro"/>

  <!-- World link
  <link name="world"/> 

   Connect base_link to the world at z = 1
  <joint name="world_to_base_link" type="fixed">
    <origin xyz="0 0 1" rpy="0 0 0"/>
    <parent link="world"/>
    <child link="base_link"/>
  </joint> -->

  <!-- Root link -->
  <link name="base_link"/> 

  <!-- Joint connecting root to base -->
  <joint name="root_to_base" type="fixed">
    <origin rpy="0 0 0" xyz="0 0 0"/>
    <parent link="base_link"/>
    <child link="base"/>
  </joint> 

  <!-- Base Link -->
  <link name="base">
    <visual>
      <geometry>
        <mesh filename="package://hexapod_sim/meshes/base.dae"/>
      </geometry>
      <origin xyz="0 0 -0.0145" rpy="${-pi/2} 0 0"/> 
    </visual>
    <collision>
      <geometry><box size="0.18 0.107 0.050"/></geometry>
      <origin xyz="0 0 0"/>
    </collision>
    <inertial>
      <mass value="0.2"/>
      <inertia ixx="0.001" ixy="0.0" ixz="0.0" iyy="0.001" iyz="0.0" izz="0.001"/>
    </inertial>
  </link>

  <!-- Joint Connecting base to the coxa -->
  <joint name="jl11" type="revolute">
    <axis xyz="1 0 0"/>
    <origin xyz="-0.09 -0.0535 -0.00075" rpy="${3*pi/4} ${pi/2} 0"/>
    <parent link="base"/>
    <child link="coxal1"/>
    <limit effort="1000.0" lower="${-pi}" upper="${pi}" velocity="${2*pi}"/>
    <dynamics damping="0.0" friction="0.0"/>
  </joint>

  <joint name="jl21" type="revolute">
    <axis xyz="1 0 0"/>
    <origin xyz="0 -0.070 -0.00075" rpy="${pi/2} ${pi/2} 0"/>
    <parent link="base"/>
    <child link="coxal2"/>
    <limit effort="1000.0" lower="${-pi}" upper="${pi}" velocity="${2*pi}"/>
    <dynamics damping="0.0" friction="0.0"/>
  </joint>

  <joint name="jl31" type="revolute">
    <axis xyz="1 0 0"/>
    <origin xyz="0.09 -0.0535 -0.00075" rpy="${pi/4} ${pi/2} 0"/>
    <parent link="base"/>
    <child link="coxal3"/>
    <limit effort="1000.0" lower="${-pi}" upper="${pi}" velocity="${2*pi}"/>
    <dynamics damping="0.0" friction="0.0"/>
  </joint>

  <joint name="jl41" type="revolute">
    <axis xyz="1 0 0"/>
    <origin xyz="-0.09 0.0535 -0.00075" rpy="-${3*pi/4} ${pi/2} 0"/>
    <parent link="base"/>
    <child link="coxal4"/>
    <limit effort="1000.0" lower="${-pi}" upper="${pi}" velocity="${2*pi}"/>
    <dynamics damping="0.0" friction="0.0"/>
  </joint>

  <joint name="jl51" type="revolute">
    <axis xyz="1 0 0"/>
    <origin xyz="0 0.070 -0.00075" rpy="${-pi/2} ${pi/2} 0"/>
    <parent link="base"/>
    <child link="coxal5"/>
    <limit effort="1000.0" lower="${-pi}" upper="${pi}" velocity="${2*pi}"/>
    <dynamics damping="0.0" friction="0.0"/>
  </joint>

  <joint name="jl61" type="revolute">
    <axis xyz="1 0 0"/>
    <origin xyz="0.09 0.0535 -0.00075" rpy="${-pi/4} ${pi/2} 0"/>
    <parent link="base"/>
    <child link="coxal6"/>
    <limit effort="1000.0" lower="${-pi}" upper="${pi}" velocity="${2*pi}"/>
    <dynamics damping="0.0" friction="0.0"/>
  </joint>

  <!-- Instantiating the leg segments -->
  <xacro:leg_segment leg_id="l1"/>
  <xacro:leg_segment leg_id="l2"/>
  <xacro:leg_segment leg_id="l3"/>
  <xacro:leg_segment leg_id="l4"/>
  <xacro:leg_segment leg_id="l5"/>
  <xacro:leg_segment leg_id="l6"/>
  
  <!-- ros2_control global configuration -->
  <ros2_control name="GazeboSimSystem" type="system">
    <hardware>
      <plugin>gz_ros2_control/GazeboSimSystem</plugin>
    </hardware>

    <!-- ros2_control joint definitions -->
    <xacro:joint_control leg_id="l1"/>
    <xacro:joint_control leg_id="l2"/>
    <xacro:joint_control leg_id="l3"/>
    <xacro:joint_control leg_id="l4"/>
    <xacro:joint_control leg_id="l5"/>
    <xacro:joint_control leg_id="l6"/>
  </ros2_control>

  <!-- Gazebo plugin for ros2_control -->
  <gazebo>
    <plugin filename="gz_ros2_control-system" name="gz_ros2_control::GazeboSimROS2ControlPlugin">
      <parameters>$(find hexapod_sim)/config/robot_controller.yaml</parameters>
    </plugin>
  </gazebo>
</robot>

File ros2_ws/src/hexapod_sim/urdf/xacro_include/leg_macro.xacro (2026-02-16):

<?xml version="1.0"?>
<robot xmlns:xacro="http://www.ros.org/wiki/xacro">

  <!-- Reusable macro for a leg segment (coxa to tip). -->
  <xacro:macro name="leg_segment" params="leg_id">

    <!-- Coxa Link -->
    <link name="coxa${leg_id}">
      <visual>
      <geometry>
        <mesh filename="package://hexapod_sim/meshes/coxa.dae"/>
      </geometry>
        <origin xyz="0.02125 0 0" rpy="${-pi/2} ${-pi/2} 0"/>
      </visual>
      <collision>
        <geometry><cylinder radius="0.0135" length="0.0385"/></geometry>
        <origin xyz="0 0 0.01925"/>
      </collision>
      <inertial>
        <mass value="0.1"/>
        <inertia ixx="0.001" ixy="0.0" ixz="0.0" iyy="0.001" iyz="0.0" izz="0.001"/>
      </inertial>
    </link>

    <!-- Joint between Coxa and Femur (j2 equivalent) -->
    <joint name="j${leg_id}2" type="revolute">
      <axis xyz="0 1 0"/>
      <origin xyz="0 0 0.0385" rpy="0 0 0"/>
      <parent link="coxa${leg_id}"/>
      <child link="femur${leg_id}"/>
      <limit effort="1000.0" lower="${-pi}" upper="${pi}" velocity="${2*pi}"/>
      <dynamics damping="0.0" friction="0.0"/>
    </joint>

    <!-- Femur Link -->
    <link name="femur${leg_id}">
      <visual>
      <geometry>
        <mesh filename="package://hexapod_sim/meshes/femur.dae"/>
      </geometry>
        <!-- <origin xyz="0 0.0315 0"/> -->
        <origin xyz="0 -0.0315 0" rpy="0 0 ${pi}"/>
      </visual>
      <collision>
        <geometry><cylinder radius="0.008" length="0.070"/></geometry>
        <origin xyz="0 0 0.035"/>
      </collision>
      <inertial>
        <mass value="0.1"/>
        <inertia ixx="0.001" ixy="0.0" ixz="0.0" iyy="0.001" iyz="0.0" izz="0.001"/>
      </inertial>
    </link>

    <!-- Joint between Femur and Tibia (j3 equivalent) -->
    <joint name="j${leg_id}3" type="revolute">
      <axis xyz="0 1 0"/>
      <origin xyz="0 0 0.070" rpy="0 0 0"/>
      <parent link="femur${leg_id}"/>
      <child link="tibia${leg_id}"/>
      <limit effort="1000.0" lower="${-pi}" upper="${pi}" velocity="${2*pi}"/>
      <dynamics damping="0.0" friction="0.0"/>
    </joint>

    <!-- Tibia Link -->
    <link name="tibia${leg_id}">
      <visual>
      <geometry>
        <mesh filename="package://hexapod_sim/meshes/tibia.dae"/>
      </geometry>
        <origin xyz="0 -0.02725 0" rpy="${pi} -0.235 0"/>
      </visual>
      <collision>
        <geometry><cylinder radius="0.004" length="0.102"/></geometry>
        <origin xyz="0 0 0.051"/>
      </collision>
      <inertial>
        <mass value="0.1"/>
        <inertia ixx="0.001" ixy="0.0" ixz="0.0" iyy="0.001" iyz="0.0" izz="0.001"/>
      </inertial>
    </link>

    <!-- Joint between Tibia and Tip (fixed) -->
    <joint name="j${leg_id}4" type="fixed">
      <origin xyz="0 0 0.102" rpy="0 0 0"/>
      <parent link="tibia${leg_id}"/>
      <child link="tip${leg_id}"/>
    </joint>

    <!-- Tip Link (colision only) -->
    <link name="tip${leg_id}">
      <collision>
        <geometry><sphere radius="0.004"/></geometry>
        <origin xyz="0 0 0"/>
      </collision>
      <inertial>
        <mass value="0.01"/>
        <inertia ixx="0.001" ixy="0.0" ixz="0.0" iyy="0.001" iyz="0.0" izz="0.001"/>
      </inertial>
    </link>
    
    <!-- Tip link physics -->
    <gazebo reference="tip${leg_id}">
      <mu1>1.2</mu1>
      <mu2>1.2</mu2>
      <kp>1000000.0</kp>
      <kd>100.0</kd>
      <minDepth>0.001</minDepth>
      <maxVel>0.1</maxVel>
      <material>Gazebo/Grey</material>
    </gazebo>
    
  </xacro:macro>

</robot>

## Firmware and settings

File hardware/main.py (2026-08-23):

#!/usr/bin/env python3
"""Servo 2040 firmware: validate and play discrete joint batches."""

import gc
import math
import sys
import time

try:
    import micropython
except ImportError:  # Allows this module to be imported by CPython tests.
    micropython = None

try:
    import ustruct as struct
except ImportError:
    import struct

try:
    from servo import ServoCluster, servo2040
except ImportError:  # Allows host-side calibration tests without board modules.
    ServoCluster = None
    servo2040 = None

try:  # The board receives main.py and protocol.py in the same directory.
    from protocol import (
        CRC_FORMAT,
        CRC_SIZE,
        HEADER_FORMAT,
        HEADER_SIZE,
        JOINT_COUNT,
        MAGIC,
        POINT_FORMAT,
        POINT_SIZE,
        PROTOCOL_VERSION,
        ProtocolError,
        crc32,
        unpack_header,
        validate_header,
    )
except ImportError:  # Host-side import from the combined repository.
    from hardware.protocol import (
        CRC_FORMAT,
        CRC_SIZE,
        HEADER_FORMAT,
        HEADER_SIZE,
        JOINT_COUNT,
        MAGIC,
        POINT_FORMAT,
        POINT_SIZE,
        PROTOCOL_VERSION,
        ProtocolError,
        crc32,
        unpack_header,
        validate_header,
    )


SERVO_COUNT = 18
CENTER_PULSE = 1500.0
MIN_PULSE = 500.0
MAX_PULSE = 2500.0
JOINT_ORDER = (
    "j11", "j21", "j31", "j41", "j51", "j61",
    "j12", "j22", "j32", "j42", "j52", "j62",
    "j13", "j23", "j33", "j43", "j53", "j63",
)
LEG_JOINT_ORDER = (
    "j11", "j12", "j13",
    "j21", "j22", "j23",
    "j31", "j32", "j33",
    "j41", "j42", "j43",
    "j51", "j52", "j53",
    "j61", "j62", "j63",
)

# These calibrated values and conversions are intentionally unchanged from the
# original Servo 2040 firmware.
CALIBRATION = {
    "j11": (10.6667, 10.8889),
    "j12": (11.1556, 10.8889),
    "j13": (10.4444, 11.3333),
    "j21": (10.3333, 11.3333),
    "j22": (10.5556, 12.0000),
    "j23": (11.1667, 11.1667),
    "j31": (11.1111, 10.6667),
    "j32": (11.1111, 10.8889),
    "j33": (11.0000, 10.6667),
    "j41": (10.5556, 10.8889),
    "j42": (11.1111, 11.0000),
    "j43": (10.7778, 11.1111),
    "j51": (12.0000, 11.1111),
    "j52": (10.6667, 11.1111),
    "j53": (10.6667, 10.8889),
    "j61": (10.8889, 11.1111),
    "j62": (11.5556, 10.4444),
    "j63": (11.0000, 10.5556),
}
ROBOT_TO_SERVO = {
    "j11": (1.0, 0.0),
    "j12": (-1.0, -84.0),
    "j13": (1.0, -121.0),
    "j21": (1.0, 0.0),
    "j22": (-1.0, -69.0),
    "j23": (1.0, -114.0),
    "j31": (1.0, 0.0),
    "j32": (-1.0, -79.0),
    "j33": (1.0, -121.0),
    "j41": (1.0, 0.0),
    "j42": (-1.0, -74.0),
    "j43": (1.0, -118.0),
    "j51": (1.0, 0.0),
    "j52": (-1.0, -67.0),
    "j53": (1.0, -112.0),
    "j61": (1.0, 0.0),
    "j62": (-1.0, -78.0),
    "j63": (1.0, -121.0),
}


class GoalReceiver:
    def __init__(self):
        if ServoCluster is None or servo2040 is None:
            raise RuntimeError("Servo 2040 modules are unavailable")
        gc.collect()
        start_pin = servo2040.SERVO_1
        end_pin = getattr(servo2040, "SERVO_%d" % SERVO_COUNT)
        self.servos = ServoCluster(pio=0, sm=0, pins=list(range(start_pin, end_pin + 1)))
        self.servos.enable_all()
        self.joint_to_channel = {joint: index for index, joint in enumerate(JOINT_ORDER)}
        self.stream = getattr(sys.stdin, "buffer", sys.stdin)
        self.last_session_id = None
        self.last_goal_id = None
        self.last_crc = None
        self.last_status = None
        self.next_point_deadline = None

    @staticmethod
    def _flush_stdout():
        flush = getattr(sys.stdout, "flush", None)
        if flush is not None:
            flush()

    def _reply(self, message):
        print(message)
        self._flush_stdout()

    @staticmethod
    def _clamp(value, minimum, maximum):
        return max(minimum, min(maximum, value))

    @staticmethod
    def _rad_to_deg(rad):
        return rad * (180.0 / math.pi)

    def robot_to_servo_deg(self, joint_name, robot_angle_rad):
        slope, intercept = ROBOT_TO_SERVO[joint_name]
        return slope * self._rad_to_deg(robot_angle_rad) + intercept

    def servo_deg_to_pulse(self, joint_name, servo_deg):
        slope_positive, slope_negative = CALIBRATION[joint_name]
        if servo_deg >= 0.0:
            return CENTER_PULSE + slope_positive * servo_deg
        return CENTER_PULSE + slope_negative * servo_deg

    def robot_angle_to_pulse(self, joint_name, robot_angle_rad):
        servo_deg = self.robot_to_servo_deg(joint_name, robot_angle_rad)
        pulse = self.servo_deg_to_pulse(joint_name, servo_deg)
        return self._clamp(pulse, MIN_PULSE, MAX_PULSE)

    def apply_goal(self, joint_values):
        pulses = [0.0] * SERVO_COUNT
        for index, joint_name in enumerate(LEG_JOINT_ORDER):
            channel = self.joint_to_channel[joint_name]
            pulses[channel] = self.robot_angle_to_pulse(joint_name, joint_values[index])
        for channel, pulse in enumerate(pulses):
            self.servos.pulse(channel, pulse)

    def _read_exact(self, count):
        chunks = []
        remaining = count
        while remaining:
            chunk = self.stream.read(remaining)
            if not chunk:
                continue
            if isinstance(chunk, str):
                chunk = chunk.encode("latin1")
            chunks.append(chunk)
            remaining -= len(chunk)
        return b"".join(chunks)

    def _read_magic(self):
        matched = 0
        while matched < len(MAGIC):
            value = self._read_exact(1)[0]
            if value == MAGIC[matched]:
                matched += 1
            else:
                matched = 1 if value == MAGIC[0] else 0
        return MAGIC

    def _wait_until(self, deadline):
        while True:
            remaining = time.ticks_diff(deadline, time.ticks_us())
            if remaining <= 0:
                return
            time.sleep_us(remaining)

    def _play_payload(self, payload, point_count, sample_period_us):
        now = time.ticks_us()
        deadline = self.next_point_deadline
        if deadline is None or time.ticks_diff(deadline, now) <= 0:
            # Start immediately for the first batch. If transfer or validation
            # missed the carried deadline, apply the first point immediately
            # and establish a fresh cadence from this arrival.
            deadline = now
        for point_index in range(point_count):
            self._wait_until(deadline)
            values = struct.unpack_from(POINT_FORMAT, payload, point_index * POINT_SIZE)
            self.apply_goal(values)
            deadline = time.ticks_add(deadline, sample_period_us)
        self.next_point_deadline = deadline

    def _read_frame(self):
        magic = self._read_magic()
        header_bytes = magic + self._read_exact(HEADER_SIZE - len(MAGIC))
        header = unpack_header(header_bytes)
        try:
            validate_header(header)
            payload = self._read_exact(header["payload_length"])
            received_crc = struct.unpack(CRC_FORMAT, self._read_exact(CRC_SIZE))[0]
            computed_crc = crc32(header_bytes + payload)
            if received_crc != computed_crc:
                raise ProtocolError("BAD_CRC")
        except ProtocolError as exc:
            raise ProtocolError(
                exc.code,
                header["session_id"],
                header["goal_id"],
            )
        return header, payload, received_crc

    def _handle_frame(self, header, payload, received_crc):
        session_id = header["session_id"]
        goal_id = header["goal_id"]
        key_matches = session_id == self.last_session_id and goal_id == self.last_goal_id
        if key_matches:
            if received_crc != self.last_crc:
                self._reply("ERR %u %u ID_REUSE" % (session_id, goal_id))
            else:
                self._reply("%s %u %u" % (self.last_status, session_id, goal_id))
            return

        if session_id == self.last_session_id and self.last_goal_id is not None:
            if goal_id < self.last_goal_id:
                self._reply("ERR %u %u STALE_GOAL" % (session_id, goal_id))
                return

        self.last_session_id = session_id
        self.last_goal_id = goal_id
        self.last_crc = received_crc
        self.last_status = "ACK"
        gc.collect()
        self._reply("ACK %u %u" % (session_id, goal_id))
        try:
            gc.disable()
            self._play_payload(
                payload,
                header["point_count"],
                header["sample_period_us"],
            )
        except Exception as exc:
            self.last_status = "ERR"
            self._reply("ERR %u %u PLAYBACK_%r" % (session_id, goal_id, exc))
            return
        finally:
            gc.enable()
        self.last_status = "DONE"
        self._reply("DONE %u %u" % (session_id, goal_id))

    def run(self):
        self._reply("READY %u" % PROTOCOL_VERSION)
        while True:
            header = None
            try:
                header, payload, received_crc = self._read_frame()
                self._handle_frame(header, payload, received_crc)
            except ProtocolError as exc:
                self._reply(
                    "ERR %u %u %s"
                    % (exc.session_id, exc.goal_id, exc.code)
                )
            except Exception as exc:
                self._reply("ERR 0 0 %r" % (exc,))


def main():
    # USB serial is also MicroPython's REPL input.  Its default Ctrl-C handler
    # treats any 0x03 in a binary frame as a KeyboardInterrupt, so disable that
    # handler before the host can queue a frame during the startup delay.
    if micropython is not None:
        micropython.kbd_intr(-1)
    time.sleep(5.0)
    GoalReceiver().run()


if __name__ == "__main__":
    main()

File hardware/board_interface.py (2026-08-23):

#!/usr/bin/env python3
"""Keyboard-to-Servo-2040 host adapter for the shared gait core."""

from __future__ import annotations

import argparse
import math
import sys
import time
from pathlib import Path

try:
    from common.keyboard_input import KeyboardInput, help_text
    from robot_core import CommandKind, ControllerMode, JointBatch, PostureAxis
    from robot_core.coordinator import HexapodCoordinator
except ImportError:
    # Support direct execution as well as ``python -m hardware.board_interface``.
    sys.path.insert(0, str(Path(__file__).resolve().parents[1]))
    from common.keyboard_input import KeyboardInput, help_text
    from robot_core import CommandKind, ControllerMode, JointBatch, PostureAxis
    from robot_core.coordinator import HexapodCoordinator

try:
    from .batch_executor import BoardBatchExecutor
except ImportError:
    from batch_executor import BoardBatchExecutor


def _describe_command(command) -> str:
    if command.kind == CommandKind.WALK:
        if command.steps is not None:
            return f"trajectory {command.trajectory_id} for {command.steps} steps"
        return f"trajectory {command.trajectory_id} continuously"
    if command.kind == CommandKind.TOGGLE_MODE:
        return "cycle normal/auto/posture mode"
    if command.kind == CommandKind.SIT_DOWN:
        return "sit down and restore standup lock"
    if command.kind == CommandKind.POSTURE:
        if command.posture_axis == PostureAxis.ELEVATION:
            return f"elevation change {command.posture_value * 1000.0:+.1f} mm"
        return (
            f"{command.posture_axis} "
            f"{math.degrees(command.posture_value):+.1f} deg"
        )
    if command.kind == CommandKind.RESET_TILT:
        return "reset posture pitch/roll"
    return command.kind


def _posture_result_notice(coordinator: HexapodCoordinator) -> str:
    result = coordinator.last_posture_result
    if result is None or not result.was_clamped:
        return ""
    if result.axis == PostureAxis.ELEVATION:
        requested = result.requested_value * 1000.0
        applied = result.applied_value * 1000.0
        unit = "mm"
    else:
        requested = math.degrees(result.requested_value)
        applied = math.degrees(result.applied_value)
        unit = "deg"
    return f"posture limit: requested {requested:+.3f} {unit}, applying {applied:+.3f} {unit}"


def parse_args():
    parser = argparse.ArgumentParser(description=__doc__)
    parser.add_argument("--port", default="/dev/ttyACM0")
    parser.add_argument("--baudrate", type=int, default=115200)
    # The firmware intentionally waits five seconds after board boot before it
    # starts its receiver, so the first acknowledgment needs a longer window.
    parser.add_argument("--response-timeout", type=float, default=8.0)
    return parser.parse_args()


def main() -> None:
    args = parse_args()
    print("Building shared gait templates...")
    coordinator = HexapodCoordinator()
    executor = BoardBatchExecutor(args.port, args.baudrate, args.response_timeout)
    quit_requested = False
    exit_code = 0

    try:
        with KeyboardInput() as keyboard:
            print(help_text("Hexapod hardware controller"))

            def poll_input() -> None:
                nonlocal quit_requested
                result = keyboard.poll(0.0)
                for notice in result.notices:
                    print(notice)
                if result.command is not None:
                    feedback = coordinator.request_with_feedback(result.command)
                    accepted = feedback.accepted
                    description = _describe_command(result.command)
                    print(
                        f"command {'accepted' if accepted else 'ignored'}: "
                        f"{description} ({feedback.code})"
                    )
                    if accepted and result.command.kind == CommandKind.TOGGLE_MODE:
                        print(
                            f"mode: {coordinator.mode}; "
                            f"requested mode: {coordinator.requested_mode}"
                        )
                    if accepted and result.command.kind == CommandKind.POSTURE:
                        notice = _posture_result_notice(coordinator)
                        if notice:
                            print(notice)
                quit_requested = quit_requested or result.quit_requested

            while not quit_requested:
                poll_input()
                batch = coordinator.next_batch()
                if batch is None:
                    time.sleep(0.02)
                    continue
                print(
                    f"goal {batch.goal_id}: {batch.phase_name}, "
                    f"{batch.point_count} points"
                )
                result = executor.execute(batch, poll_input)
                coordinator.complete_batch(batch.goal_id, result.succeeded)
                if not result.succeeded:
                    print(
                        f"goal {batch.goal_id} failed: "
                        f"{result.status} {result.detail}",
                        file=sys.stderr,
                    )
                    exit_code = 1
                    break
                if coordinator.is_stationary:
                    print(f"stationary; mode: {coordinator.mode}")
                elif coordinator.mode == ControllerMode.POSTURE and coordinator.is_idle:
                    pose = coordinator.posture.current_pose
                    print(
                        "posture hold: "
                        "elevation="
                        f"{coordinator.posture.current_elevation * 1000.0:.2f} mm, "
                        f"pitch={math.degrees(pose.pitch):+.2f} deg, "
                        f"roll={math.degrees(pose.roll):+.2f} deg"
                    )
    except KeyboardInterrupt:
        exit_code = 130
    finally:
        executor.close()
    raise SystemExit(exit_code)


if __name__ == "__main__":
    main()

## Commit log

2025-06-14 Initial commit.
    [hexapod.urdf.xacro, joint_control_macro.xacro, leg_macro.xacro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]
2025-07-24 Fixed kinematics.
2026-02-09 Minor urdf change.
    [leg_macro.xacro]
2026-02-12 Cleanup and first step (robot model, IK and action server).
    [hexapod.urdf.xacro]
2026-02-12 Small fix.
    [hexapod.urdf.xacro]
2026-02-16 Changed speed and started building fast gait.
    [hexapod.urdf.xacro, leg_macro.xacro]
2026-02-16 Added elevation/pitch node.
2026-02-18 Updated trajectory switching logic.
2026-03-07 Split gait control between Pi and thin board driver
2026-03-07 Align Pi gait controller with original template flow
2026-03-10 Add print-only gait test harness
2026-03-12 Changed dead servo.
2026-03-17 Rewrite tip delta in leg coordinates
2026-03-18 Add sampled base pose trajectory execution
2026-03-23 Add pitch nod trajectory
2026-03-28 Changed control buttons.
2026-08-18 Unify hardware and simulation gait controllers
    [hexapod.urdf.xacro, joint_control_macro.xacro, leg_macro.xacro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]
2026-08-19 Tune posture motion and add tilt reset
    [board_interface.py]
2026-08-19 Rename standup flow and preserve modes
2026-08-20 Bundle Servo 2040 MicroPython runtime
2026-08-21 Document ROSBug CAD electronics and BOM
2026-08-21 Add printable CAD files and project overview
    [base_.STL, bearing_holder+bearing_holder_2.STL, bearing_link.STL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]
2026-08-21 Make BOM documentation visitor focused
2026-08-23 Improve Servo 2040 recovery and posture limits
2026-08-23 Reduce Servo 2040 batch handoff latency
